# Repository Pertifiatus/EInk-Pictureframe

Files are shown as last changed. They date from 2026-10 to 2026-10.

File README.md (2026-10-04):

# E-Ink Picture Frame

A battery-powered **color e-paper picture frame** that rotates itself between portrait and landscape. Pictures are uploaded and managed in a web interface hosted by the frame itself.

## Features

- **7.3" Spectra 6 e-paper** (GDEP073E01, 800×480, 6 colors). It keeps the image without using power.
- **Motorized rotation:** a 28BYJ-48 stepper with a 40:1 worm gear turns the frame by 90°. An IMU (MPU-9250) detects the orientation and fine-tunes the position.
- **Built-in web app:** the frame opens its own WiFi access point (`http://192.168.4.1`) where you can:
  - upload and delete pictures (thumbnails are generated automatically)
  - create playlists and pick the current picture
  - set the clock, change settings, calibrate the motor
- **Deep sleep:** the DS3231 RTC wakes the frame to change the picture. A button wakes it up to start the WiFi interface.
- Battery monitoring with a low-battery indicator on the picture, plus an RGB status LED.
- Images, playlists and settings are stored on a microSD card.

## Hardware

| Part | Details |
|---|---|
| MCU | ESP32-S3 (with PSRAM) |
| Display | GDEP073E01 via DESPI-C02 adapter (SPI) |
| Storage | microSD (shares the SPI bus) |
| RTC / IMU | DS3231 + MPU-9250 (I2C) |
| Motor | 28BYJ-48 + ULN2003, worm gear 40:1 |
| Power | Li-ion battery |
| PCB | Custom KiCad board (`Ki-Cad/EInk-Rahmen`) |

All pins are defined in `config.h`.

## Repository structure

```
Arduino/
  eink_frame_V11/       Latest firmware (config.h, display/motor modules, web UI)
  eink_frame_V2..V10/   Earlier versions / milestones
  eink_frame_V10_WOmotor/  Variant without rotation motor
  Test/                 Hardware tests (display, SD, I2C scanner, LED, stepper)
3D Files/Frame.f3z      Fusion 360 frame model
Ki-Cad/EInk-Rahmen/     Schematic and PCB
```

## Getting started

1. Install these libraries: **GxEPD2**, **ESPAsyncWebServer** + **AsyncTCP** (mathieucarbou), **RTClib**, **AccelStepper**.
2. Board: *ESP32S3 Dev Module* with PSRAM enabled.
3. Copy `eink_frame.html` to the SD card as `/index.html` and create an `/images` folder.
4. Adjust the WiFi name/password in `config.h`, then upload `eink_frame_V11.ino`.
5. Press the WiFi button, connect to the frame's network and open `http://192.168.4.1`.

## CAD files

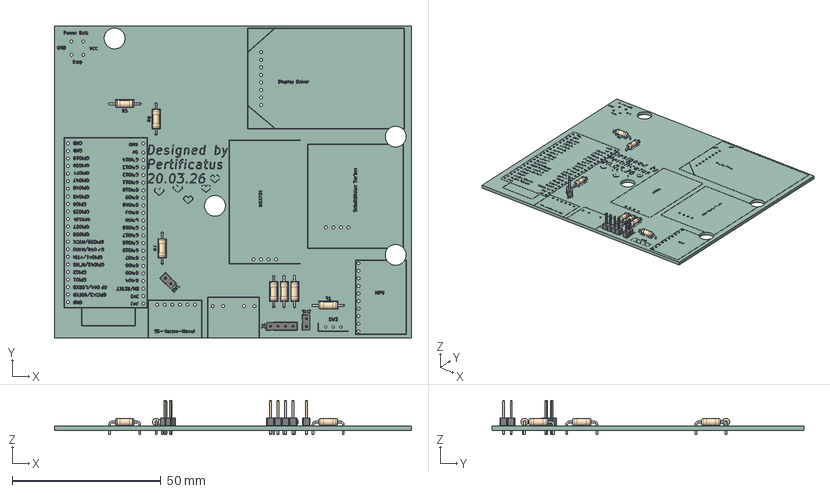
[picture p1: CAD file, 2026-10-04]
Ki-Cad/EInk-Rahmen/EInk-Rahmen.step
120.0 x 105.0 x 11.5 mm
PinHeader_1x02_P2.54mm_Vertical x 2
R_Axial_DIN0207_L6.3mm_D2.5mm_P10.16mm_Horizontal x 7
PinHeader_1x04_P2.54mm_Vertical
EInk-Rahmen_silkscreen
EInk-Rahmen_PCB

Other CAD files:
3D Files/Frame.f3z

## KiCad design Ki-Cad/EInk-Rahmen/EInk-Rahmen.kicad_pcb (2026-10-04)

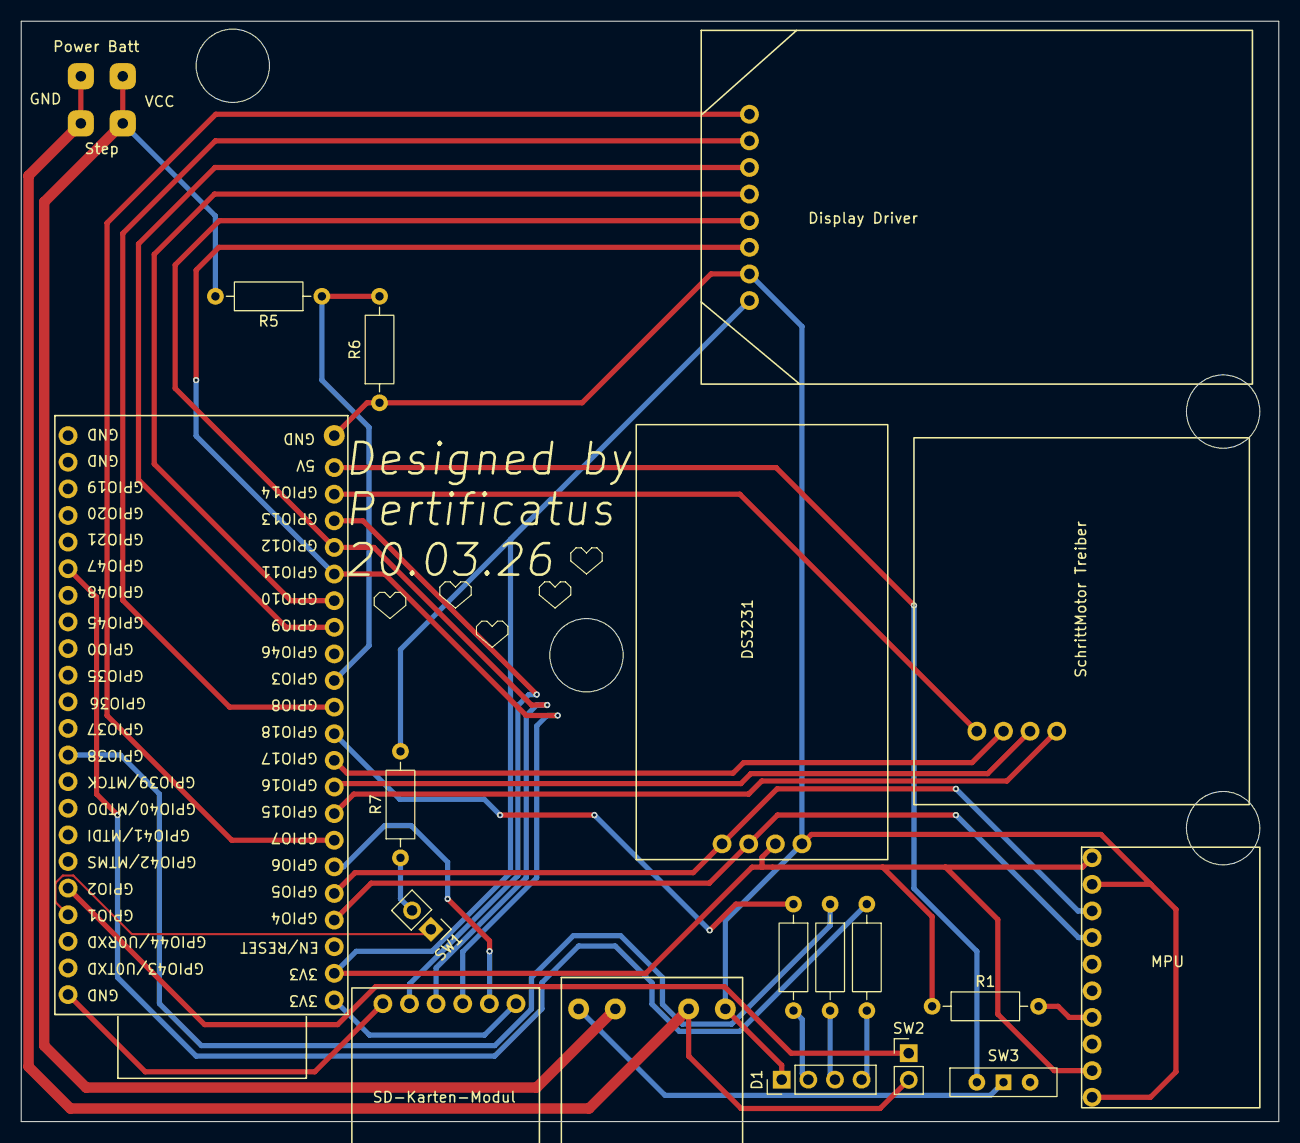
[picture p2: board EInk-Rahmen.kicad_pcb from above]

Board: 2 copper layers, 120.0 x 105.0 mm, 19 parts (0 on the bottom side), 31 nets.

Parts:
D1: LED_ABGR; PinHeader_1x04_P2.54mm_Vertical
J1: Conn_01x04; Time Module
J2: Conn_01x10; MPU Modul
J3: Conn_01x06; SD Karten Modul
J4: Conn_01x08; Display Treiber
J5: Conn_01x04; Schrittmotor Treiber
J6: Conn_01x02; Power Management
R1, R7: 10k; R_Axial_DIN0207_L6.3mm_D2.5mm_P10.16mm_Horizontal
R2: R150; R_Axial_DIN0207_L6.3mm_D2.5mm_P10.16mm_Horizontal
R3, R4: R100; R_Axial_DIN0207_L6.3mm_D2.5mm_P10.16mm_Horizontal
R5, R6: 100k; R_Axial_DIN0207_L6.3mm_D2.5mm_P10.16mm_Horizontal
SW1: Kugelschalter; PinHeader_1x02_P2.54mm_Vertical
SW2: Wlan Taster; PinHeader_1x02_P2.54mm_Vertical
SW3: SW_Wuerth_450301014042; SW_Slide-03_Wuerth-WS-SLTV_10x2.5x6.4_P2.54mm
U1: ESP32-S3-DevKitC
U2: TP4056 USB-C Charging

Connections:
+4V: J6.1, R5.2, U2.2 (Battery_+)
GND: J6.2, SW2.2, U2.3 (Battery_-)
unnamed: D1.1 (A), J1.4, J2.2, J2.10, J3.6, J4.7, R6.1, U1.44 (GND), U2.4 (Out_-)
unnamed: D1.2 (BK), R4.2
unnamed: D1.3 (GK), R3.2
unnamed: D1.4 (RK), R2.2
unnamed: J1.1, J2.3, U1.5 (GPIO5/ADC1_CH4)
unnamed: J1.2, J2.4, U1.4 (GPIO4/ADC1_CH3)
unnamed: J1.3, J2.1, J2.9, J3.1, J4.8, R1.1, R7.2, U1.2 (3V3)
unnamed: J2.7, R1.2
unnamed: J3.2, U1.6 (GPIO6/ADC1_CH5)
unnamed: J3.3, J4.6, U1.17 (GPIO11/ADC2_CH0)
unnamed: J3.4, J4.5, U1.18 (GPIO12/ADC2_CH1)
unnamed: J3.5, U1.19 (GPIO13/ADC2_CH2)
unnamed: J4.1, U1.7 (GPIO7/ADC1_CH6)
unnamed: J4.2, U1.12 (GPIO8/ADC1_CH7)
unnamed: J4.3, U1.15 (GPIO9/ADC1_CH8)
unnamed: J4.4, U1.16 (GPIO10/ADC1_CH9)
unnamed: J5.1, U1.20 (GPIO14/ADC2_CH3)
unnamed: J5.2, U1.10 (GPIO17/ADC2_CH6)
unnamed: J5.3, U1.9 (GPIO16/ADC2_CH5/32K_N)
unnamed: J5.4, U1.8 (GPIO15/ADC2_CH4/32K_P)
unnamed: R7.1, SW1.2
unnamed: SW3.1 (B), U2.1 (Out_+)
unnamed: SW3.2 (C), U1.21 (5V)
unnamed: SW1.1, U1.41 (GPIO1/ADC1_CH0)
unnamed: SW2.1, U1.40 (GPIO2/ADC1_CH1)
unnamed: R5.1, R6.2, U1.13 (GPIO3/ADC1_CH2)
unnamed: R4.1, U1.11 (GPIO18/ADC2_CH7)
unnamed: R3.1, U1.35 (GPIO38)
unnamed: R2.1, U1.28 (GPIO47)

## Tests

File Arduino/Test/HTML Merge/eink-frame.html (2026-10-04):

Bilderrahmen

7.3″ Spectra 6 · ESP32-S3

28.9 MB frei

78.0%

Bereit

Display Vorschau

Nächster Wechsel: 02:00 Uhr

Display wird aktualisiert…

Ausstehend

1 / 5

Anwenden

Einstellungen

Bilder pro Tag

1× 2× 4× 6× Custom

Wechsel um 02:00 und 14:00 Uhr

+ Hinzufügen

Erste Wechsel-Uhrzeit

Gerätestatus

Akkustand 78%

Bilder auf SD 5 Bilder

SD-Karte belegt 5.5 MB / 32 GB

SD-Speicher 32.0 GB frei

Nächster Wakeup 02:00 Uhr

Letzter Wechsel –

WLAN Deep Sleep Timeout

2 Min 5 Min 10 Min 30 Min

AP schaltet sich nach 5 Minuten ohne Aktivität ab

RTC Uhrzeit

--:--:--

Nicht synchronisiert

DS3231 Status

Nicht sync.

Browserzeit übernehmen Manuell

⚠️ Zeit wird nur gesetzt wenn WLAN aktiv ist. Der DS3231 hält die Zeit auch ohne Strom (CR2032).

Optionen

Zufällige Reihenfolge

Wiedergabe-Format

Alle Quer Hoch

Alle Bilder werden abgespielt

Aktive Playlist

Bild hochladen Datei wählen

Foto hierher ziehen

oder klicken zum Auswählen · JPEG, PNG, WEBP

−90° +90° Reset Abbrechen Hochladen

Zuschnitt

Auto Manuell

Format

Querformat Hochformat

E-Ink Vorschau-Filter

Dithering (Floyd-Steinberg)

Stärke 100%

Konvertiere zu BMP…

Wiedergabeliste 5 Bilder

Alle Quer Hoch

Drag & Drop

Neue Playlist ✕

Name

Bilder auswählen 0 ausgewählt

Alle Quer Hoch

Löschen

Abbrechen Speichern

Bild-Einstellungen ✕

Bild_01.bmp

~1.1 MB · BMP 24bit

Format / Ausrichtung

Querformat Hochformat

Löschen Fertig

Bild löschen?

Dieses Bild wird dauerhaft von der SD-Karte gelöscht und kann nicht wiederhergestellt werden.

Abbrechen Löschen

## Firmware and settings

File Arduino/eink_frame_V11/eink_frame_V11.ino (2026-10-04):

// eink_frame_V11.ino
//
// Benötigte Bibliotheken:
//   - ESPAsyncWebServer  (mathieucarbou/ESPAsyncWebServer)
//   - AsyncTCP           (mathieucarbou/AsyncTCP)
//   - GxEPD2             (ZinggJM/GxEPD2)
//   - SD (Arduino built-in)
//   - RTClib             (Adafruit)
//   - AccelStepper       (Mike McCauley)

#include <Arduino.h>
#include <Wire.h>
#include <SPI.h>
#include <SD.h>
#include <WiFi.h>
#include <ESPAsyncWebServer.h> 
#include <RTClib.h>
#include "esp_task_wdt.h"
#include <esp_sleep.h>
#include <driver/rtc_io.h>
#include <math.h>
#include "config.h"
#include "display_module.h"
#include "motor_module.h"

// ─── WebServer ────────────────────────────────────────────────────────────────
AsyncWebServer server(80);

// ─── RTC ──────────────────────────────────────────────────────────────────────
RTC_DS3231 rtc;

// JSON-Body (Playlists, Bibliotheks-Einstellungen) direkt in eine Temp-Datei streamen:
// keine Größengrenze durch RAM-Puffer, und das Original wird erst ersetzt wenn alle
// Bytes geschrieben sind → nie eine abgeschnittene/kaputte JSON-Datei.
struct BodyFile { File f; bool ok = false; const char* tmp; const char* path; };
static BodyFile g_plBody  = { File(), false, "/playlists.tmp",    "/playlists.json"    };
static BodyFile g_libBody = { File(), false, "/lib_settings.tmp", "/lib_settings.json" };

static void bodyChunk(BodyFile& b, uint8_t* data, size_t len, size_t index, size_t total) {
  if (index == 0) {
    if (b.f) b.f.close();
    b.f  = SD.open(b.tmp, FILE_WRITE);
    b.ok = (bool)b.f;
  }
  if (b.f && b.f.write(data, len) != len) b.ok = false;  // SD voll / Schreibfehler
  if (index + len >= total && b.f) b.f.close();
}

static bool bodyCommit(BodyFile& b) {
  bool ok = b.ok;
  b.ok = false;
  if (!ok) { SD.remove(b.tmp); return false; }
  SD.remove(b.path);
  return SD.rename(b.tmp, b.path);
}

// Dateinamen aus Requests: nur einfache Namen, kein Pfad (verhindert "../config.json")
static bool safeName(const String& n) {
  return n.length() > 0 && n.length() < 20 &&
         n.indexOf('/') < 0 && n.indexOf('\\') < 0 && n.indexOf("..") < 0;
}


// ─── index.html im PSRAM ──────────────────────────────────────────────────────
static uint8_t* htmlBuffer = nullptr;
static size_t   htmlSize   = 0;

// ─── Image-Liste Cache im PSRAM ───────────────────────────────────────────────
// Beim AP-Start komplett aufgebaut, bei Upload/Löschen gezielt angepasst.
// /api/status liest nur diese Werte → das Status-Polling greift nie auf die SD zu.
#define MAX_IMG 999                       // Bildnummern 001..999
static char*    g_imageListJson    = nullptr;
static size_t   g_imageListJsonLen = 0;
static int      g_imageCount       = 0;
static float    g_sdTotalMb        = 0;
static float    g_sdFreeMb         = 0;
static bool     g_imgNumUsed[MAX_IMG + 1]; // belegte Nummern NNN.bmp → freie Nummer ohne SD-Suche

void loadIndexHtml() {
  File f = SD.open("/index.html", FILE_READ);
  if (!f) { Serial.println("[!] index.html nicht gefunden"); return; }
  htmlSize   = f.size();
  htmlBuffer = (uint8_t*)ps_malloc(htmlSize);
  if (!htmlBuffer) { Serial.println("[!] Kein PSRAM für index.html"); f.close(); return; }
  f.read(htmlBuffer, htmlSize);
  f.close();
  Serial.printf("index.html: %u Bytes im PSRAM\n", (unsigned)htmlSize);
}

void buildImageListCache() {
  String json = "[";
  bool first = true;
  g_imageCount = 0;
  memset(g_imgNumUsed, 0, sizeof(g_imgNumUsed));
  File dir = SD.open("/images");
  if (dir) {
    while (true) {
      File entry = dir.openNextFile();
      if (!entry) break;
      if (entry.isDirectory()) { entry.close(); continue; }
      String fname = entry.name();
      entry.close();
      if (!fname.endsWith(".bmp") && !fname.endsWith(".BMP")) continue;
      int slash = fname.lastIndexOf('/');
      if (slash >= 0) fname = fname.substring(slash + 1);

      char path[32];
      snprintf(path, sizeof(path), "/images/%s", fname.c_str());
      int32_t w = 0, h = 0;
      if (!getBmpSize(path, w, h)) continue;
      const char* orient = (abs(h) > abs(w)) ? "portrait" : "landscape";

      int num = atoi(fname.c_str());
      if (num > 0 && num <= MAX_IMG) g_imgNumUsed[num] = true;
      g_imageCount++;

      json += first ? "" : ",";
      json += "{\"name\":\"" + fname + "\",\"orientation\":\"" + String(orient) + "\"}";
      first = false;
    }
    dir.close();
  }
  json += "]";

  // usedBytes() durchsucht die ganze FAT → nur hier, nicht bei jedem Status-Poll
  uint64_t total = SD.totalBytes();
  g_sdTotalMb = total / 1048576.0f;
  g_sdFreeMb  = (total - SD.usedBytes()) / 1048576.0f;

  if (g_imageListJson) { free(g_imageListJson); g_imageListJson = nullptr; }
  g_imageListJsonLen = json.length();
  g_imageListJson = (char*)ps_malloc(g_imageListJsonLen + 1);
  if (g_imageListJson) {
    memcpy(g_imageListJson, json.c_str(), g_imageListJsonLen + 1);
    Serial.printf("[cache] Image-Liste: %u Bytes gecacht\n", (unsigned)g_imageListJsonLen);
  } else {
    Serial.println("[!] Kein PSRAM für Image-Liste");
  }
}

// ─── Upload-State ─────────────────────────────────────────────────────────────
static File uploadFile;
static int  uploadImageNum = -1;
static bool uploadOk       = false;
static bool uploadPortrait = false;
static size_t uploadBytes  = 0;
static const char* uploadErr = "";
static File thumbFile;

// Upload/Löschen: Cache gezielt anpassen statt alle Bilder neu zu scannen
// (Neuaufbau öffnet jede Datei + durchsucht die FAT → bei hunderten Bildern Sekunden pro Upload)
static void imageCacheAdd(int num, bool portrait, size_t bytes) {
  char entry[64];
  int n = snprintf(entry, sizeof(entry), "%s{\"name\":\"%03d.bmp\",\"orientation\":\"%s\"}]",
                   g_imageCount ? "," : "", num, portrait ? "portrait" : "landscape");
  char* p = g_imageListJson ? (char*)ps_realloc(g_imageListJson, g_imageListJsonLen + n + 1) : nullptr;
  if (!p) { buildImageListCache(); return; }
  memcpy(p + g_imageListJsonLen - 1, entry, n + 1);  // schließendes ']' überschreiben
  g_imageListJson    = p;
  g_imageListJsonLen += n - 1;
  g_imageCount++;
  g_imgNumUsed[num] = true;
  g_sdFreeMb -= bytes / 1048576.0f;
}

static void imageCacheRemove(const char* fname, size_t bytes) {
  char key[32];
  snprintf(key, sizeof(key), "{\"name\":\"%s\"", fname);
  char* s = g_imageListJson ? strstr(g_imageListJson, key) : nullptr;
  char* e = s ? strchr(s, '}') : nullptr;
  if (!e) { buildImageListCache(); return; }
  e++;
  if (*e == ',') e++;                         // folgendes Komma mitnehmen
  else if (s > g_imageListJson + 1) s--;      // letztes Element: vorheriges Komma mitnehmen
  memmove(s, e, strlen(e) + 1);
  g_imageListJsonLen = strlen(g_imageListJson);
  g_imageCount--;
  int num = atoi(fname);
  if (num > 0 && num <= MAX_IMG) g_imgNumUsed[num] = false;
  g_sdFreeMb += bytes / 1048576.0f;
}

// ─── Globale State-Variablen (vor loadConfig, da dort verwendet) ──────────────
static volatile bool  g_displayPending = false;
static volatile char  g_displayPath[32] = "";
static volatile bool  g_displayBusy    = false;
static volatile char  g_displayPhase[12] = ""; // "rotating" | "rendering" | ""
static char           g_currentImage[32] = "";
static char           g_activePlId[64]   = "";   // ID der aktiven Playlist
static bool           g_shuffle          = false;
static uint8_t        g_wifiTimeoutMin   = 5;    // WLAN AP-Timeout in Minuten
static uint8_t        g_imgPerDay        = 1;    // Bildwechsel pro Tag (0 = Custom)
static uint8_t        g_startHour        = IMAGE_CHANGE_HOUR;  // Erste Wechsel-Uhrzeit
static char           g_customTimes[64]  = "";   // Custom-Modus: "HH:MM,HH:MM,..." (kommagetrennt)
static char           g_lastChange[20]   = "";   // Zeitpunkt letzter Bildwechsel "YYYY-MM-DD HH:MM"
static char           g_orientFilter[12] = "";   // "landscape", "portrait", "" = alle
static char           g_frameOrient[12]  = "";   // aktuelle Rahmen-Orientierung ("portrait"/"landscape"/"")
static int32_t        g_motorSteps90     = 0;    // kalibrierte Schritte für 90° (0 = noch nicht kalibriert)
static bool           g_autoRotate       = true; // Auto-Rotate Feature aktiv
static volatile uint32_t g_lastActivityMs    = 0;    // Zeitstempel letzter Browser-Ping (für Inaktivitäts-Timeout)
static volatile bool     g_motorCalibPending = false; // POST /api/motor/calibrate → loop() führt aus
static volatile bool     g_motorBusy         = false; // Motor läuft gerade
static volatile char     g_motorCalibPhase[32] = ""; // Aktueller Kalibrierungsschritt für /api/status
static volatile bool     g_motorMovePending  = false; // POST /api/motor/move → loop() führt aus
static volatile int32_t  g_motorMoveSteps    = 0;    // Schritte für manuellen Motorlauf
static volatile bool     g_shutdownPending   = false; // POST /api/shutdown → sofort schlafen
RTC_DATA_ATTR static bool g_lowBatIconShown  = false; // Blitz ist auf dem Display (überlebt Deep Sleep)

// ─── RGB LED ──────────────────────────────────────────────────────────────────
// LEDC-PWM: 8 Bit, 5 kHz – reicht für flimmerfreies Dimmen der LED
#define LED_FREQ      5000
#define LED_RES       8      // 8 Bit → Werte 0–255

void ledInit() {
  ledcAttach(PIN_LED_R, LED_FREQ, LED_RES);
  ledcAttach(PIN_LED_G, LED_FREQ, LED_RES);
  ledcAttach(PIN_LED_B, LED_FREQ, LED_RES);
  ledcWrite(PIN_LED_R, 0);
  ledcWrite(PIN_LED_G, 0);
  ledcWrite(PIN_LED_B, 0);

  // Onboard-WS2812 (GPIO 48) wird nicht verwendet, bleibt aber ohne Init
  // in einem undefinierten Zustand und leuchtet sonst dauerhaft weiß.
  // Einmalig ein "Aus"-Frame senden, um sie zuverlässig auszuschalten.
  neopixelWrite(48, 0, 0, 0);
}

// Setzt eine feste Farbe (0–255 je Kanal)
void ledSet(uint8_t r, uint8_t g, uint8_t b) {
  ledcWrite(PIN_LED_R, r);
  ledcWrite(PIN_LED_G, g);
  ledcWrite(PIN_LED_B, b);
}

void ledOff() { ledSet(0, 0, 0); }

// Zwei weiche rote Sinuspulse — signalisiert WLAN-AP deaktiviert
void ledDoubleRedPulse() {
  const uint32_t PULSE_MS  = 600;  // Dauer eines Pulses (Auf + Ab)
  const uint32_t PAUSE_MS  = 250;  // Pause zwischen den Pulsen
  const uint8_t  MAX_BRIGHT = 180; // Spitzenhelligkeit (gedämpftes Rot)

  for (int i = 0; i < 2; i++) {
    uint32_t start = millis();
    while (millis() - start < PULSE_MS) {
      float t      = (float)(millis() - start) / PULSE_MS * (float)M_PI;
      float bright = sinf(t);
      bright       = bright * bright; // Gamma → weicherer Abfall
      ledSet((uint8_t)(bright * MAX_BRIGHT), 0, 0);
      delay(16); // ~60 Hz
    }
    ledOff();
    if (i < 1) delay(PAUSE_MS);
  }
}

// Kurzes Aufblitzen einer Farbe (blockierend, nur beim Boot)
void ledFlash(uint8_t r, uint8_t g, uint8_t b, uint16_t ms = 300) {
  ledSet(r, g, b);
  delay(ms);
  ledOff();
}

// Blaues Pulsieren für AP-Modus — kurzer Puls, dann lange Pause (Stromsparen)
// Zyklus: 1,5 s Puls → 5,5 s aus → repeat (LED an nur ~21% der Zeit)
void ledBreathing() {
  static uint32_t lastMs = 0;
  uint32_t now = millis();
  if (now - lastMs < 20) return; // 50 Hz Update
  lastMs = now;

  const uint32_t CYCLE_MS = 7000; // Gesamtzyklus 7 s
  const uint32_t PULSE_MS = 1500; // davon 1,5 s Pulsierphase

  uint32_t pos = now % CYCLE_MS;
  if (pos >= PULSE_MS) { ledOff(); return; } // lange Pause → aus

  // Halbe Sinuskurve (0→max→0) innerhalb der Pulsierphase
  float t      = (float)pos / PULSE_MS * (float)M_PI;
  float bright = sinf(t);
  bright       = bright * bright; // Gamma-Korrektur → weicherer Abfall
  ledSet(0, 0, (uint8_t)(bright * 70.0f));
}

// ─── Konfig-Datei /config.json ────────────────────────────────────────────────
// Format: {"current_image":"/images/001.bmp","active_playlist":"12345"}

// Einfacher Bool-Extraktor für JSON-Boolean-Felder
static bool jsonExtractBool(const String& json, const char* key) {
  int ki = json.indexOf(key);
  if (ki < 0) return false;
  int colon = json.indexOf(':', ki + strlen(key));
  if (colon < 0) return false;
  int vs = colon + 1;
  while (vs < (int)json.length() && json[vs] == ' ') vs++;
  return json.substring(vs, vs + 4) == "true";
}

// Einfacher String-Extraktor für JSON-String-Felder (kein ArduinoJson nötig)
static bool jsonExtractStr(const String& json, const char* key, char* out, size_t outSize) {
  int ki = json.indexOf(key);
  if (ki < 0) return false;
  int colon = json.indexOf(':', ki + strlen(key));
  if (colon < 0) return false;
  int vs = colon + 1;
  while (vs < (int)json.length() && json[vs] == ' ') vs++;
  if (json[vs] == '"') {
    int s = vs + 1;
    int e = json.indexOf('"', s);
    if (e <= s || (e - s) >= (int)outSize) return false;
    json.substring(s, e).toCharArray(out, outSize);
  } else if (isdigit(json[vs])) {
    int s = vs, e = vs;
    while (e < (int)json.length() && isdigit(json[e])) e++;
    if ((e - s) <= 0 || (e - s) >= (int)outSize) return false;
    json.substring(s, e).toCharArray(out, outSize);
  } else {
    return false;  // null oder anderer Nicht-String-Wert
  }
  return true;
}

void loadConfig() {
  File f = SD.open("/config.json", FILE_READ);
  if (!f) return;
  String json = f.readString();
  f.close();
  if (jsonExtractStr(json, "\"current_image\"",  g_currentImage, sizeof(g_currentImage)))
    Serial.printf("[config] current_image: %s\n", g_currentImage);
  if (jsonExtractStr(json, "\"active_playlist\"", g_activePlId,   sizeof(g_activePlId)))
    Serial.printf("[config] active_playlist: %s\n", g_activePlId);
  g_shuffle = jsonExtractBool(json, "\"shuffle\"");
  Serial.printf("[config] shuffle: %s\n", g_shuffle ? "true" : "false");

  char tmp[8];
  if (jsonExtractStr(json, "\"wifi_timeout\"", tmp, sizeof(tmp))) g_wifiTimeoutMin = atoi(tmp);
  if (jsonExtractStr(json, "\"img_per_day\"",  tmp, sizeof(tmp))) g_imgPerDay      = atoi(tmp);
  if (jsonExtractStr(json, "\"start_hour\"",   tmp, sizeof(tmp))) g_startHour      = atoi(tmp);
  jsonExtractStr(json, "\"custom_times\"",  g_customTimes,  sizeof(g_customTimes));
  jsonExtractStr(json, "\"last_change\"",   g_lastChange,   sizeof(g_lastChange));
  jsonExtractStr(json, "\"orient_filter\"", g_orientFilter, sizeof(g_orientFilter));
  jsonExtractStr(json, "\"frame_orient\"",  g_frameOrient,  sizeof(g_frameOrient));
  if (json.indexOf("\"auto_rotate\"") >= 0)
    g_autoRotate = jsonExtractBool(json, "\"auto_rotate\"");
  char stepsStr[12] = "";
  if (jsonExtractStr(json, "\"motor_steps_90\"", stepsStr, sizeof(stepsStr)))
    g_motorSteps90 = atol(stepsStr);
  Serial.printf("[config] wifi_timeout: %u min, img_per_day: %u, start_hour: %u\n",
                g_wifiTimeoutMin, g_imgPerDay, g_startHour);
  Serial.printf("[config] frame_orient: %s, motor_steps_90: %ld\n",
                g_frameOrient[0] ? g_frameOrient : "(unbekannt)", (long)g_motorSteps90);
}

void saveConfig() {
  File f = SD.open("/config.json", FILE_WRITE);
  if (!f) { Serial.println("[config] Schreiben fehlgeschlagen"); return; }
  f.printf("{\n"
           "  \"current_image\": \"%s\",\n"
           "  \"active_playlist\": %s%s%s,\n"
           "  \"shuffle\": %s,\n"
           "  \"wifi_timeout\": %u,\n"
           "  \"img_per_day\": %u,\n"
           "  \"start_hour\": %u,\n"
           "  \"custom_times\": \"%s\",\n"
           "  \"last_change\": \"%s\",\n"
           "  \"orient_filter\": \"%s\",\n"
           "  \"frame_orient\": \"%s\",\n"
           "  \"auto_rotate\": %s,\n"
           "  \"motor_steps_90\": %ld\n"
           "}\n",
           g_currentImage,
           g_activePlId[0] ? "\"" : "", g_activePlId[0] ? g_activePlId : "null", g_activePlId[0] ? "\"" : "",
           g_shuffle ? "true" : "false",
           g_wifiTimeoutMin, g_imgPerDay, g_startHour, g_customTimes, g_lastChange,
           g_orientFilter, g_frameOrient, g_autoRotate ? "true" : "false", (long)g_motorSteps90);
  f.close();
}

// Aktuellen RTC-Zeitstempel in g_lastChange schreiben ("YYYY-MM-DD HH:MM")
void stampLastChange() {
  if (rtc.lostPower()) return;
  DateTime now = rtc.now();
  snprintf(g_lastChange, sizeof(g_lastChange), "%04u-%02u-%02u %02u:%02u",
           now.year(), now.month(), now.day(), now.hour(), now.minute());
}

// ─── Deep Sleep ───────────────────────────────────────────────────────────────
// sleepSecs: Sekunden bis zum Timer-Wakeup (automatischer Bildwechsel)
// Wakeup-Quellen: Timer (Bildwechsel) + EXT0 GPIO 2 LOW (Taster → AP-Modus)
void goToDeepSleep(uint32_t sleepSecs) {
  ledOff(); // LED vor dem Schlafen ausschalten
  mpuSleep(); // MPU zieht sonst ~3,5 mA durch den gesamten Deep Sleep
  Serial.printf("[sleep] Schlafe %lu s (naechster Wechsel in %lu min)\n",
                sleepSecs, sleepSecs / 60);
  Serial.flush();

  WiFi.softAPdisconnect(true);
  delay(100);            // AP-Clients Zeit zum Trennen geben
  WiFi.mode(WIFI_OFF);
  delay(100);            // WiFi-Treiber vollständig herunterfahren lassen

  // Taster GPIO 2: RTC-Pullup aktivieren damit Pin definiert HIGH liegt
  rtc_gpio_pullup_en((gpio_num_t)PIN_WAKEUP_BTN);
  rtc_gpio_pulldown_dis((gpio_num_t)PIN_WAKEUP_BTN);
  esp_sleep_enable_ext0_wakeup((gpio_num_t)PIN_WAKEUP_BTN, 0); // LOW = gedrückt

  // Timer für automatischen Bildwechsel
  esp_sleep_enable_timer_wakeup((uint64_t)sleepSecs * 1000000ULL);

  esp_deep_sleep_start(); // kehrt nicht zurück
}

// ─── Schlafzeit berechnen ─────────────────────────────────────────────────────
// Gibt Sekunden bis zum nächsten geplanten Bildwechsel zurück.
// Regular-Modus: g_imgPerDay gleichmäßige Slots ab g_startHour.
// Custom-Modus:  g_customTimes = "HH:MM,HH:MM,..." (kommagetrennt).
// Fallback bei defekter/nicht gesetzter RTC: 3600 s (1 Stunde).

// RTC-Sekunden seit Mitternacht, -1 wenn RTC ungültig / nicht gesetzt
static int32_t rtcDaySeconds() {
  if (rtc.lostPower()) { Serial.println("[sleep] RTC ungueltig"); return -1; }
  DateTime now = rtc.now();
  if (now.year() < 2024) { Serial.println("[sleep] RTC nicht gesetzt"); return -1; }
  return (int32_t)now.hour() * 3600 + now.minute() * 60 + now.second();
}
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
void loop() {
  if (g_displayPending && !g_displayBusy && !g_motorBusy) {
    g_displayPending = false;
    g_displayBusy    = true;

    char path[32];
    strncpy(path, (const char*)g_displayPath, sizeof(path));
    Serial.printf("[loop] Display-Auftrag: %s\n", path);

    rotateAndShow(path);
    g_displayBusy = false;
  }

  // ── Motor-Kalibrierung via /api/motor/calibrate ──────────────────────────
  if (g_motorCalibPending && !g_motorBusy && !g_displayBusy) {
    g_motorCalibPending = false;
    g_motorBusy         = true;
    Serial.println("[loop] Motor-Kalibrierung gestartet");

    motorInit();
    esp_task_wdt_add(NULL);
    bool calibEndedPortrait = false;
    int32_t measured = motorCalibrateFull(g_motorCalibPhase, &calibEndedPortrait);
    esp_task_wdt_delete(NULL);
    strcpy((char*)g_motorCalibPhase, "");

    if (measured > 0) {
      g_motorSteps90 = measured;
      strcpy(g_frameOrient, calibEndedPortrait ? "portrait" : "landscape");
      saveConfig();
      Serial.printf("[loop] Kalibrierung OK: %ld Schritte, Endlage: %s\n",
                    (long)measured, calibEndedPortrait ? "portrait" : "landscape");
      ledFlash(0, 255, 0, 400); // Grün: Erfolg
    } else {
      Serial.println("[loop] Kalibrierung fehlgeschlagen");
      g_frameOrient[0] = '\0';  // Lage unbekannt → nächster Bildwechsel kalibriert neu
      saveConfig();
      ledFlash(255, 0, 0, 400); // Rot: Fehler
    }
    g_motorBusy = false;
  }

  // ── Manueller Motorlauf via /api/motor/move ───────────────────────────────
  if (g_motorMovePending && !g_motorBusy && !g_displayBusy) {
    g_motorMovePending = false;
    g_motorBusy        = true;
    motorInit();
    esp_task_wdt_add(NULL);
    motorManualMove((int32_t)g_motorMoveSteps);
    esp_task_wdt_delete(NULL);
    g_motorBusy = false;
  }

  // ── Manueller Shutdown via /api/shutdown ─────────────────────────────────
  if (g_shutdownPending && !g_displayBusy) {
    Serial.println("[shutdown] Manueller Shutdown – gehe sofort schlafen");
    server.end();
    delay(100);
    goToDeepSleep(calcSleepSeconds());
  }

  // Blaues Pulsieren im AP-Modus (nur wenn kein Rendering/Motor läuft)
  if (!g_displayBusy && !g_motorBusy) ledBreathing();

  // ── Taster: WLAN manuell abschalten ────────────────────────────────────────
  if (!g_displayBusy && !g_motorBusy && digitalRead(PIN_WAKEUP_BTN) == LOW) {
    delay(50); // Entprellen
    if (digitalRead(PIN_WAKEUP_BTN) == LOW) {
      Serial.println("[AP] Taster gedrückt – WLAN wird deaktiviert");
      server.end();
      ledDoubleRedPulse();
      goToDeepSleep(calcSleepSeconds());
    }
  }

  // ── Inaktivitäts-Timeout: kein Browser-Ping → Deep Sleep ─────────────────
  // g_lastActivityMs einmal lesen (volatile) → lokale Variable, dann konsistent verwenden
  uint32_t _last = (uint32_t)g_lastActivityMs;
  if (!g_displayBusy && _last > 0) {
    uint32_t timeoutMs = (uint32_t)g_wifiTimeoutMin * 60000UL;
    uint32_t _now  = millis();
    uint32_t _diff = _now - _last;
    if (_diff >= timeoutMs) {
      Serial.printf("[AP] Inaktivitaet > %u min – gehe schlafen\n", g_wifiTimeoutMin);
      server.end();
      ledDoubleRedPulse();
      goToDeepSleep(calcSleepSeconds());
    }
  }
}

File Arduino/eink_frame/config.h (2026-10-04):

// config.h
// Zentrale Konfigurationsdatei — alle Pins, Konstanten und Pfade an einem Ort.
#pragma once

// ─── Display (DESPI-C02 via SPI) ────────────────────────────────────────────
#define PIN_EPD_MOSI    11
#define PIN_EPD_SCK     12
#define PIN_EPD_CS      10
#define PIN_EPD_DC       9  // LOW = Befehl, HIGH = Bilddaten
#define PIN_EPD_RST      8
#define PIN_EPD_BUSY     7  // HIGH solange das Display noch arbeitet

// ─── SD-Karte (SPI, shared bus) ─────────────────────────────────────────────
// MOSI + SCK werden mit dem Display geteilt, nur CS ist getrennt
#define PIN_SD_CS        6
#define PIN_SD_MISO     13  // Nur SD-Karte sendet Daten zurück, Display nicht

// ─── I2C (DS3231 RTC + MPU-9250, shared bus) ────────────────────────────────
// DS3231: Adresse 0x68 | MPU-9250: AD0 auf HIGH → Adresse 0x69 (kein Konflikt)
// GPIO 19/20 NICHT verwenden — das sind USB D-/D+ am ESP32-S3!
#define PIN_I2C_SDA      4
#define PIN_I2C_SCL      5

// ─── Schrittmotor 28BYJ-48 via ULN2003 ─────────────────────────────────────
// Direkt an Akkuspannung (3,7–4,2V) betreiben — kein Boost-Converter nötig
#define PIN_MOTOR_IN1   14
#define PIN_MOTOR_IN2   17
#define PIN_MOTOR_IN3   16
#define PIN_MOTOR_IN4   15

// Schrittmotor-Konfiguration (AccelStepper)
#define MOTOR_MAX_SPEED       500.0f   // Schritte/Sek — langsam für elegante Bewegung
#define MOTOR_ACCELERATION    200.0f   // Schritte/Sek² — sanftes Anfahren/Abbremsen
#define MOTOR_STEPS_DEFAULT  2048      // Fallback-Wert für 90° (überschrieben durch Kalibrierung)

// ─── Orientierungssensor ────────────────────────────────────────────────────
// Kugelschalter SW-520D in 45° Diagonale montiert
// Ändert Zustand bei jeder 90° Drehung des Rahmens
// RTC-GPIO → reagiert auf beide Flanken im Deep Sleep
#define PIN_BALL_SWITCH  1   // RTC-GPIO, EXT1 Wakeup

// ─── Sonstiges ──────────────────────────────────────────────────────────────
#define PIN_BATTERY_ADC  3   // Spannungsteiler 100kΩ/100kΩ → halbiert Akkuspannung (GPIO 19 = USB D-, nicht verwenden!)
#define PIN_WAKEUP_BTN   2   // EXT0 Wakeup aus Deep Sleep (WLAN-Taster)
#define PIN_LED_B       47   // RGB LED Rot   + 100Ω Vorwiderstand
#define PIN_LED_G       38   // RGB LED Grün  + 100Ω Vorwiderstand
#define PIN_LED_R       18   // RGB LED Blau  + 100Ω Vorwiderstand (GPIO 48 = onboard WS2812, nicht verwenden!)

// ─── Akku-Messung ───────────────────────────────────────────────────────────
#define BATTERY_DIVIDER_RATIO   2.0f    // 100kΩ/100kΩ → Messwert × 2 = echte Spannung
#define BATTERY_MAX_VOLTAGE     4.2f
#define BATTERY_MIN_VOLTAGE     3.0f
#define ADC_REF_VOLTAGE         3.3f
#define ADC_RESOLUTION          4095.0f // 12-Bit ADC

// ─── WLAN Access Point ──────────────────────────────────────────────────────
// ESP32 hostet eigenes Netz — erreichbar unter http://192.168.4.1
#define WIFI_AP_SSID      "Bilderrahmen"
#define WIFI_AP_PASSWORD  "12345678"        // min. 8 Zeichen für WPA2
#define WIFI_AP_CHANNEL   1
#define WIFI_AP_MAX_CONN  2
#define WIFI_TIMEOUT_MS   (5UL * 60 * 1000) // 5 Min, dann AP aus → Deep Sleep

// ─── Bildwechsel ────────────────────────────────────────────────────────────
#define IMAGE_CHANGE_HOUR      2  // Uhrzeit des ersten Wechsels (0–23)
#define IMAGE_CHANGES_PER_DAY  1  // Erlaubte Werte: 1, 2, 3, 4, 6, 8, 12, 24
                                  // 1 → alle 24h | 2 → alle 12h | 4 → alle 6h

// ─── Motorlauf & Orientierungswechsel ───────────────────────────────────────
#define BALL_SWITCH_SETTLE_MS  500   // Wartezeit nach Wakeup bis Kugel zur Ruhe kommt
#define MPU_ANGLE_THRESHOLD    85.0f // Grad — Motor stoppt wenn MPU diesen Winkel meldet
#define MOTOR_POWER_OFF_DELAY  200   // ms nach Motorstop bevor Pins auf LOW (Strom sparen)

// ─── SD-Karte: Dateipfade ───────────────────────────────────────────────────
#define SD_IMAGES_DIR   "/images"
#define SD_CONFIG_FILE  "/config.json"
#define SD_INDEX_HTML   "/index.html"

// ─── Display-Auflösung ──────────────────────────────────────────────────────
#define DISPLAY_WIDTH   800
#define DISPLAY_HEIGHT  480

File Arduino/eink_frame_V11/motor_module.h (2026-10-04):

// motor_module.h
// Phase 4: Schrittmotor-Steuerung und MPU-9250 Orientierungserkennung
//
// Getriebe: Schneckenrad z=40, 1-gängige Schnecke → Übersetzung 40:1
// 28BYJ-48 HALF4WIRE: 4096 Schritte/Motorumdrehung × 40 = 40.960 Schritte für 90°
//
// Ablauf Kalibrierung (motorCalibrateFull):
//   1. Orientierung erkennen (MPU, vorzeichenbehaftet) → grüner LED-Flash
//   2. Exakt auf 0°/90° ausrichten, dann 90° in Gegenrichtung drehen (Schritte zählen)
//   3. Schritte speichern, dann zurückdrehen zur Startorientierung
//
// Normalbetrieb (motor_steps_90 bekannt):
//   motorRotate(steps, dir) → Schnelldrehung mit gespeicherten Schritten
//                           → IMU-Feinjustierung der letzten Grad
//
// Benötigte Bibliothek: AccelStepper (Mike McCauley)

// Forward-Deklarationen für LED-Funktionen (definiert in eink_frame_V11.ino)
extern void ledFlash(uint8_t r, uint8_t g, uint8_t b, uint16_t ms);
extern void ledSet(uint8_t r, uint8_t g, uint8_t b);

#pragma once
#include <Arduino.h>
#include <Wire.h>
#include <AccelStepper.h>
#include <math.h>
#include "esp_task_wdt.h"
#include <SD.h>
#include "config.h"

// ─── Motor-Log (auch ohne USB lesbar) ─────────────────────────────────────────
// Alle Motor-Meldungen gehen zusätzlich nach /motor_log.txt auf der SD,
// im Browser lesbar unter http://192.168.4.1/api/log.
// Gepuffert im RAM und nur geschrieben wenn der Motor steht (mlogFlush in
// motorPowerOff / setCalibPhase) → SD-Zugriffe bremsen den Motor nicht.
static String g_mlogBuf;

static void mlog(const char* fmt, ...) {
  char line[192];
  va_list ap;
  va_start(ap, fmt);
  vsnprintf(line, sizeof(line), fmt, ap);
  va_end(ap);
  Serial.print(line);
  g_mlogBuf += line;
}

void mlogFlush() {
  if (g_mlogBuf.length() == 0) return;
  File f = SD.open("/motor_log.txt", FILE_APPEND);
  if (f) { f.print(g_mlogBuf); f.close(); }
  g_mlogBuf = "";
}
// ─── MPU-9250 Register ────────────────────────────────────────────────────────
#define MPU_ADDR         0x69   // AD0 auf HIGH → Adresse 0x69
#define MPU_REG_PWR      0x6B   // PWR_MGMT_1: 0x00 = wach
#define MPU_REG_ACCEL    0x3B   // ACCEL_XOUT_H (6 Bytes big-endian: Ax, Ay, Az)

// Portrait ≈ 0°, Landscape ≈ 90°
#define PORTRAIT_ANGLE_THRESH  MPU_PORTRAIT_THRESHOLD  // direkt gemessener Portrait-Schwellwert

// Fahrstrecke bis zur Richtungsprüfung im laufenden Suchlauf: ~5° (2° liegt im MPU-Rauschen)
#define MOTOR_PROBE_STEPS   (MOTOR_STEPS_DEFAULT / 18)   // ≈ 2275 Schritte ≈ 5°

// Abfrage-Intervall während des Kalibrierlaufs
#define MOTOR_CHECK_STEPS   (MOTOR_STEPS_DEFAULT / 90)   // ≈ 455 Schritte ≈ 1°

// Max. Schritte für Kalibrierlauf: 2,25 × 90° (auf dem Kopf → aufrecht = 180° + Reserve)
#define MOTOR_SEARCH_MAX    (MOTOR_STEPS_DEFAULT * 2 + MOTOR_STEPS_DEFAULT / 4)

// ─── Schrittmotor-Instanz ─────────────────────────────────────────────────────
// 28BYJ-48 mit ULN2003: HALF4WIRE = Halbschrittmodus
// Reihenfolge IN1, IN3, IN2, IN4 → korrekte Sequenz für 28BYJ-48
static AccelStepper g_stepper(
  AccelStepper::HALF4WIRE,
  PIN_MOTOR_IN1, PIN_MOTOR_IN3, PIN_MOTOR_IN2, PIN_MOTOR_IN4
);

// ─── MPU-9250 aufwecken ───────────────────────────────────────────────────────
void mpuInit() {
  // 100 kHz statt 400 kHz: robuster gegen Störungen vom Motor (Log zeigte kaputte Reads)
  Wire.setClock(100000);
  for (int i = 0; i < 3; i++) {
    Wire.beginTransmission(MPU_ADDR);
    Wire.write(MPU_REG_PWR);
    Wire.write(0x00);
    if (Wire.endTransmission(true) == 0) { mlog("[MPU] OK\n"); delay(50); return; }
    delay(10);
  }
  mlog("[MPU] WARNUNG: nicht gefunden\n");
  delay(50);
}
// ─── MPU-9250 schlafen legen ──────────────────────────────────────────────────
// Wach zieht der MPU ~3,5 mA – auch im Deep Sleep des ESP32 (Reset-Wert = wach).
// Sleep-Bit (0x40) → ~8 µA. mpuInit() weckt ihn beim nächsten Motorlauf wieder.
void mpuSleep() {
  Wire.beginTransmission(MPU_ADDR);
  Wire.write(MPU_REG_PWR);
  Wire.write(0x40);
  Wire.endTransmission(true);
}

// ─── Neigungswinkel lesen ─────────────────────────────────────────────────────
// Vorzeichenbehaftet, -180°..+180°:
//   0° = Portrait aufrecht, +90° = richtiges Landscape, ±180° = auf dem Kopf.
// (V10 nutzte |Ax|,|Ay| → "auf dem Kopf" las sich ebenfalls als 0° und wurde
//  als Portrait akzeptiert.) Vorzeichen über MPU_AX_SIGN / MPU_AY_SIGN in config.h.

// Ein Rohwert-Paar lesen. false bei I2C-Fehler oder unplausiblem Wert:
// der Rahmen steht senkrecht → |(ax, ay)| ≈ 1 g (16384 bei ±2 g). Gestörte Reads
// lieferten z.B. ax=511 ay=-1 bzw. ay=0 → wäre sonst exakt "89,8°" = falsches Ziel.
static bool mpuReadRaw(int16_t& ax, int16_t& ay) {
  Wire.beginTransmission(MPU_ADDR);
  Wire.write(MPU_REG_ACCEL);
  if (Wire.endTransmission(false) != 0) return false;
  if (Wire.requestFrom(MPU_ADDR, (uint8_t)6, (bool)true) < 6) return false;
  uint8_t b[6];
  for (int i = 0; i < 6; i++) b[i] = Wire.read();  // feste Reihenfolge (nicht 2× read() in einem Ausdruck)
  ax = (int16_t)((b[0] << 8) | b[1]);
  ay = (int16_t)((b[2] << 8) | b[3]);
  float g = sqrtf((float)ax * ax + (float)ay * ay);
  return g > 0.75f * 16384.0f && g < 1.25f * 16384.0f;
}

// Median aus 3 gültigen Messungen (bis zu 8 Versuche) → einzelne Ausreißer fallen raus.
// Gibt NAN zurück, wenn keine einzige gültige Messung zustande kommt.
static float mpuReadAngle(bool logRaw = false) {
  float a[3];
  int n = 0;
  int16_t ax = 0, ay = 0;
  for (int tries = 0; tries < 8 && n < 3; tries++) {
    if (!mpuReadRaw(ax, ay)) { delayMicroseconds(300); continue; }
    a[n++] = atan2f((float)(MPU_AX_SIGN * ax), (float)(MPU_AY_SIGN * ay)) * 180.0f / (float)M_PI
           - MPU_OFFSET;  // Montage-Schräglage korrigieren
  }
  if (n == 0) { mlog("[MPU] keine gueltige Messung\n"); return NAN; }

  float angle = a[0];
  if (n == 3) {  // Median = der Wert zwischen den anderen beiden
    angle = fmaxf(fminf(a[0], a[1]), fminf(fmaxf(a[0], a[1]), a[2]));
  }
  if (logRaw) mlog("[MPU] ax=%d ay=%d → Winkel=%.1f° (%d/3 gueltig)\n", ax, ay, angle, n);
  return angle;
}
// Winkeldifferenz auf -180..+180 normieren
static float wrapDeg(float d) {
  while (d > 180.0f)  d -= 360.0f;
  while (d < -180.0f) d += 360.0f;
  return d;
}

// Liegt der Winkel im Zielfenster? Portrait: |a| < 0,5°. Landscape: 88°..135° (nur richtige Seite).
static bool mpuAtTarget(float a, bool portrait) {
  if (isnan(a)) return false;
  return portrait ? (fabsf(a) < PORTRAIT_ANGLE_THRESH)
                  : (a >= MPU_ANGLE_THRESHOLD && a < 135.0f);
}

// ─── Motor initialisieren ─────────────────────────────────────────────────────
void motorInit() {
  g_stepper.setMaxSpeed(MOTOR_MAX_SPEED);
  g_stepper.setAcceleration(MOTOR_ACCELERATION);
  g_stepper.disableOutputs();
  mlog("[Motor] initialisiert\n");
}
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

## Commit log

2026-10-04 Added code for all versions
    [EInk-Rahmen.kicad_pcb, EInk-Rahmen.kicad_sch, EInk-Rahmen.step]
2026-10-04 Added CAD models
    [Frame.f3z]
